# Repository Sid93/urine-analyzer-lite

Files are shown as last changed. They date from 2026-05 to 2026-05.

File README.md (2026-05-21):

# Urine Analyzer Lite

> Compact, automated urine dipstick reader by **Levram Lifesciences**.  
> Single-strip, N20-motor-driven, ESP32-S3 based with thermal print output.

---

## Overview

The Urine Analyzer Lite reads standard 10-pad reagent dipsticks using dual TCS34725 RGB color sensors and classifies results for 10 analytes. A compact N20 gear motor steps the strip under the optical head at controlled speed. Results print via an integrated CSN-A2 thermal printer.

**Key specs:**

| Parameter | Value |
|---|---|
| MCU | ESP32-S3-DevKitC-1 (Xtensa dual-core 240 MHz, 8 MB flash) |
| Sensors | TCS34725 ×2, SHT31, BH1750, ADS1115, HX711 |
| Display | 3.5" SPI TFT (ILI9488) + XPT2046 touch — see `hardware/ENGINEERING_REVIEW.md` |
| Motor | GA12-N20 6V 200RPM with Hall encoder + MX1508 H-bridge |
| Printer | CSN-A2 58mm thermal (ESC/POS) |
| Power | 3.7V 2000mAh LiPo → TP4056 USB-C charger → S13V25F5 5V regulator |
| Sterilization | 275nm UV-C LED (10s cycle post-scan) |
| Analytes | Leukocytes, Nitrites, Urobilinogen, Protein, pH, Blood, Specific Gravity, Ketones, Bilirubin, Glucose |
| Estimated BOM | ~$387 per unit (prototype); target <$250 at 50-unit volume |

---

## Repository Structure

```
urine-analyzer-lite/
├── hardware/
│   ├── schematic/
│   │   ├── gen_schematic.py          # KiCad schematic generator
│   │   └── urine_analyzer_lite.kicad_sch
│   └── cad/
│       └── main_chassis.scad         # OpenSCAD enclosure (all 3D-printed parts)
├── firmware/
│   └── main/
│       ├── main.ino                  # Arduino sketch (state machine)
│       ├── config.h                  # Pin map and tunable constants
│       ├── sensors.h                 # All sensor drivers
│       ├── motor.h                   # N20 motion control + homing
│       ├── analysis.h                # HSV pad classification (10 analytes)
│       └── printer.h                 # ESC/POS thermal print
├── bom/
│   └── bom.csv                       # Full bill of materials (~40 items)
├── TODO.md                           # Project checklist
└── README.md
```

---

## Hardware

### Schematic
Open in KiCad 7+:
```
File → Open → hardware/schematic/urine_analyzer_lite.kicad_sch
```
To regenerate after edits:
```bash
cd hardware/schematic && python3 gen_schematic.py
```

### CAD
Open in OpenSCAD ≥ 2021.01:
```
hardware/cad/main_chassis.scad
```
All 3D-printable parts are exported from one file. Render individual modules:
```
openscad -o chassis_base.stl main_chassis.scad
```

**Print settings:**

| Part | Material | Infill | Layer |
|---|---|---|---|
| Chassis base, MCU tray, dipstick tray | PLA | 20% | 0.2 mm |
| Optical chamber, UV-C shield | Black PLA | 100% | 0.1 mm |
| Sensor mounts, printer bracket, belt parts | PETG | 30% | 0.2 mm |

---

## Firmware

### Requirements
- Arduino IDE ≥ 2.3 with ESP32 board package ≥ 2.0.14
- Board: **ESP32S3 Dev Module** — Flash: 8MB, PSRAM: OPI, USB: Hardware CDC

### Libraries (Arduino Library Manager)
```
Adafruit TCS34725      >= 1.4.2
Adafruit ADS1X15       >= 2.5.0
Adafruit SHT31         >= 2.2.2
BH1750 by Christopher Laws >= 1.3.0
HX711 by bogde         >= 0.7.5
```

### Flash
1. Open `firmware/main/main.ino` in Arduino IDE  
2. Select board and port  
3. Upload

### Calibration (required before first use)
1. **White standard** — place Spectralon pad under optical head; record R/G/B values in `config.h` (`CAL_R/G/B_WHITE`)
2. **Scale** — place known weight on scale platform; adjust `scale.set_scale()` factor in `sensors.h`
3. **Motor steps** — measure real pad pitch with calipers; adjust `TICKS_PER_PAD` in `config.h`
4. **Hue ranges** — run known positive/negative strips; refine `PAD_TABLE[]` in `analysis.h`

---

## Operation

1. Insert dipstick tray with strip face-up
2. Place sample cup on weight sensor (minimum 1 g detected)
3. Press scan button
4. Device homes, steps across all 10 pads, classifies, prints report
5. UV-C sterilization cycle runs automatically (10 s)
6. Remove strip; device returns to IDLE

---

## Bill of Materials

See [`bom/bom.csv`](bom/bom.csv) — estimated prototype total: **$387 USD**.

---

## License

Hardware and firmware © Levram Lifesciences. All rights reserved.  
*For clinical use by qualified personnel only.*

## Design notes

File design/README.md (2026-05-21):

# Design (Stage 3) — Blueprint export

Device design iteration exported from **Blueprint** (lite / single-strip variant).
This is the design-intent source that the hardware (`../hardware/`) and BOM (`../bom/`)
are derived from.

## Contents (`blueprint/`)
- `CONFIG.json` — full device configuration (components, parameters)
- `ELECTRICAL_CONNECTIONS.json` — wiring / net definitions
- `MECHANICAL_CONNECTIONS.json` — mechanical assembly relationships
- `PARTS.csv` — parts list with categories, quantities, costs, source URLs
- `GUIDE.md` — fabrication / wiring / bring-up / assembly checklist
- `VISUAL.png` — rendered layout

> A second, fuller Blueprint export (10P / larger variant) exists outside the repo at
> `~/Desktop/Sids Gdrive/urine_dipstick_analyzer_files (1)/`. Not imported here — this repo
> tracks the **lite** design. Import it if the project consolidates on that variant.

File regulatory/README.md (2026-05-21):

# Regulatory & Quality — Stage 0 Foundation

> Backfilled 2026-05-21. These documents establish the foundation that should have preceded
> the hardware/firmware work. Per the project's hard-gate rule, **Stage 0 gates everything**
> and **design freeze (Stage 5) gates all validation**.

| # | Document | Purpose | Status |
|---|---|---|---|
| 00 | [Target Product Profile](00_target_product_profile.md) | Intended use, analytes, claims, performance targets | DRAFT — open issues |
| 01 | [CDSCO Classification & Pathway](01_cdsco_classification.md) | IVD class (best-guess B), licensing route | DRAFT — needs consultant confirmation |
| 02 | [Standards Matrix](02_standards_matrix.md) | Applicable / excluded standards, tailored | DRAFT |
| 03 | [Risk Management File (ISO 14971)](03_risk_management_iso14971.md) | Hazard analysis / FMEA seed | DRAFT skeleton |
| 04 | [Freedom-to-Operate](04_freedom_to_operate.md) | Preliminary optics patent search | PRELIMINARY |

## The three decisions that gate everything else
1. **Strips: proprietary vs commercial?** (TPP §4) — changes scope, dossier, and timeline most.
2. **Confirm CDSCO class via pre-submission** before generating validation data.
3. **Keep or drop UV-C sterilization?** (Risk H1 / Standards §UV-C) — highest novelty-vs-burden tradeoff.

## Disclaimers
- Best-guess classifications and the FTO read are **not** legal/regulatory opinions.
- Engage a CDSCO regulatory consultant and (before launch/export) a patent attorney.

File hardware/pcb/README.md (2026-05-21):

# PCB — Urine Analyzer Lite (Design A)

A **starting board** generated from the netlist model via KiCad's `pcbnew` Python API.
All 31 footprints are placed and net-assigned; the board is **not yet routed**.

## Files
- `build_pcb.py` — generator (run with KiCad's bundled Python; needs `pcbnew`).
- `urine_analyzer_lite.kicad_pcb` — the board (31 footprints, real footprints, nets assigned).
- `urine_analyzer_lite.kicad_pro` — project file (open this in KiCad).
- `urine_analyzer_lite_render_top.png` — 3D render (top).
- `DRC_report.txt` / `drc.json` — DRC output.

## Validation (KiCad 10.0.3)
- **Schematic parity: 0 mismatches** — the board's connectivity matches the schematic exactly.
- **104 unconnected items** — this is the **unrouted ratsnest** (expected; the engineer routes it).
- **214 DRC violations** — all are **placement-density cosmetics** from the auto-grid layout:
  `silk_over_copper`/`silk_overlap` (ref-text overlap), `courtyards_overlap`,
  `pth_inside_courtyard`, a few `clearance`/`solder_mask_bridge`. They disappear once parts are
  spread out and routed. **None are structural / netlist errors.**

## What the engineer does
1. Open the project in KiCad 10. **Confirm footprints** — modules are generic 2.54mm pin
   headers; verify each header's **pin ORDER against the module datasheet/silkscreen**
   (the auto-assignment uses the netlist order, see `footprints.py` + `../netlist/NETLIST.md`).
2. Re-place parts sensibly (optical chamber sensors together, printer/motor power near the
   regulator, keep UV-C/printer high-current away from sensor analog lines).
3. Add **power planes** (GND / +5V / +3V3), route — wide traces for motor/printer/UV-C per
   `../POWER_BUDGET.md`. Add mounting holes to the chassis stand-offs.
4. **DRC → 0**, then export Gerbers + drill + position:
   ```
   kicad-cli pcb export gerbers -o gerbers/ urine_analyzer_lite.kicad_pcb
   kicad-cli pcb export drill   -o gerbers/ urine_analyzer_lite.kicad_pcb
   ```

## Regenerate
```bash
/Applications/KiCad.app/Contents/Frameworks/Python.framework/Versions/3.9/bin/python3 build_pcb.py
```

> Starting board for engineer verification, not a finished layout. Placement, routing, footprint
> confirmation (esp. module pin order), stackup, and DRC sign-off are the engineer's.

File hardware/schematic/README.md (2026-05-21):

# Schematic — Urine Analyzer Lite (Design A)

`urine_analyzer_lite.kicad_sch` is a **machine-generated, ERC-validated** schematic produced
from the same netlist model as `../netlist/` (single source of truth = `config.h` master pin map).

## Files
- `gen_schematic.py` — generator. Imports `../netlist/gen_netlist.py` (the component/pin/net model).
- `urine_analyzer_lite.kicad_sch` — the schematic (KiCad 9/10, format 20250114).
- `urine_analyzer_lite_schematic.pdf` — rendered view (open without KiCad).
- `ERC_report.txt` — KiCad ERC output.

## Validation (done with KiCad 10.0.3 `kicad-cli`)
- **Netlist cross-check:** KiCad's exported netlist matches the model **39/39 nets** by ref **and pad**.
- **ERC:** **0 errors**, ~18 warnings — all benign: `lib_symbol_issues (ual)` for the custom
  module symbols (embedded, render fine) and `isolated_pin_label: VBUS` (expected single-node
  USB input). Jellybean symbols + all footprints now resolve cleanly.

## Symbols & footprints
- **14 jellybean discretes** (R×5, C, C_Polarized×2, LED, Battery_Cell, Thermistor, SW_Push×3)
  use **real KiCad library symbols** (`Device:*`, `Switch:*`), embedded from KiCad's shared libs.
- **Modules + the MOSFET** use generic rectangular symbols (no stock symbol exists for dev-boards/
  breakouts). Their pins are numbered by **PCB pad** so schematic↔board align.
- **Every symbol has a real footprint** assigned (see `../footprints.py`), so "Update PCB from
  Schematic" carries footprints. Module footprints are 2.54mm pin headers — verify pin ORDER
  against each module's datasheet.

## How connectivity is represented
Every pin carries a **global label = its net name**, placed exactly on the pin's connection point.
KiCad joins global labels by name across the sheet, so the netlist is exact. There are
intentionally **no drawn wires** — a connection-by-label schematic, valid and ERC-clean, but
visually a net-label list rather than a hand-drawn ratsnest (the engineer can redraw with wires;
connectivity won't change).

## What the engineer does next
1. Open in KiCad 9/10. Review nets against `../ENGINEERING_REVIEW.md` and `config.h`.
2. **Swap generic symbols for proper library symbols** where preferred, and **assign real
   footprints** (placeholders listed in `../netlist/NETLIST.md`).
3. Optionally redraw with wires for readability (connectivity won't change — it's label-driven).
4. Re-run ERC, then proceed to PCB layout → DRC → Gerbers (see `../netlist/README.md`).

> This is an AI-generated first draft for verification, not a released design. It is electrically
> correct per the model, but symbol/footprint choices and the physical design need engineer sign-off.

## Regenerate
```bash
python3 gen_schematic.py            # rewrites urine_analyzer_lite.kicad_sch
# then, with KiCad installed:
kicad-cli sch erc urine_analyzer_lite.kicad_sch
kicad-cli sch export pdf -o urine_analyzer_lite_schematic.pdf urine_analyzer_lite.kicad_sch
```

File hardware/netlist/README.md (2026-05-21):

# Netlist — Urine Analyzer Lite (Design A)

Generated from the `config.h` master pin map (see `../ENGINEERING_REVIEW.md §3`).

## Files
- `gen_netlist.py` — generator (single source of truth: the `COMPONENTS` model).
- `urine_analyzer_lite.net` — KiCad legacy netlist. **Import path to PCB layout.**
- `NETLIST.md` — human-readable component + net table for review.

## Regenerate
```bash
python3 gen_netlist.py
```

## How the engineer uses this (Stage 4 verification → layout)
1. **Review** `NETLIST.md` against `ENGINEERING_REVIEW.md` and the firmware `config.h`.
2. In KiCad, create a project; **Pcbnew → File → Import Netlist → `urine_analyzer_lite.net`**.
   This brings in all components + the ratsnest (connectivity) for layout.
3. **Assign real footprints** — the footprints in the netlist are descriptive placeholders.
   Map each to a verified KiCad footprint (or a custom one for the dev-board/module headers).
4. Alternatively, draw the schematic in KiCad's Eeschema from `NETLIST.md`, annotate, and run
   **ERC** — this is the formal Stage 4 schematic-verification step.
5. Then PCB: power planes (GND / +5V / +3V3), wide traces for motor/printer/UV-C, mounting
   holes to the chassis stand-offs, **DRC → 0 errors**, export Gerbers + assembly BOM.

## Known notes for the engineer
- **VBUS** is a single-node net by design: 5V USB input lives on the TP4056 module's own
  USB-C connector; not separately modeled.
- **Footprints are placeholders.** Most parts here are breakout boards / dev modules wired via
  pin headers — expect to create header footprints rather than use bare-IC footprints.
- **Decoupling:** bulk caps (C1/C2 at +5V, C3 at +3V3) are included for the printer/motor
  pulse loads; add per-module 100 nF decoupling at layout as standard practice.
- **Power sequencing constraint** (from `POWER_BUDGET.md`): firmware must keep printer / UV-C /
  heavy-motor phases sequential so peak 5V load stays within the regulator rating.
- This netlist is a **first-draft for verification**, not a released design. An electronics
  engineer must confirm pin mappings, footprints, and run ERC/DRC before fabrication.

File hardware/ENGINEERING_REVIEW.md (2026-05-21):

# Stage 4 Engineering Review — Master Pin Map & Netlist Reconciliation

> Status: DRAFT for engineer verification (2026-05-21).
> **This document is the Stage 4 gate.** Before any PCB layout, an electronics engineer must
> resolve the items marked 🔴 and sign off on the master pin map below. AI-generated; treat as
> a high-quality first draft, NOT release-ready (see project key cautions).

## 0. Why this exists
The electrical design currently lives in three places that **disagree with each other**:
- `firmware/main/config.h` — the firmware pin map (internally consistent, testable)
- `design/blueprint/ELECTRICAL_CONNECTIONS.json` — Blueprint netlist
- `bom/bom.csv` + `README.md` — the parts list

There is also a non-matching legacy schematic (`hardware/schematic/...kicad_sch`, a graphical
mock-up with no netlist) and a separate, divergent camera-based KiCad project
(`~/Desktop/urine_dipstick_analyzer_pcb/`, ESP32-WROOM + OV2640). None can go to PCB as-is.

**Decision: `config.h` is adopted as the source of truth** (it is concrete, internally
consistent, and what the firmware actually drives), corrected for the hardware-validity issues
in §2. All other sources are reconciled to it.

## 1. Source conflicts (resolved → see §3)

| Item | config.h | Blueprint | BOM/README | Resolution |
|---|---|---|---|---|
| Motor driver | MX1508 | L298N mini | MX1508 | **MX1508** (cheaper, adequate for N20; matches firmware/BOM) |
| I2C SDA/SCL | 21 / **22** | 1 / 2 | — | Move to valid pins — see §2.1 |
| Motor IN1/IN2 | 18 / 8 | 4 / 5 | — | Use config.h, remapped in §3 |
| Encoder A/B | 15 / 7 | 6 / 7 | — | Use §3 map |
| HX711 DT/SCK | 4 / 5 | 19 / 20 | — | config.h (Blueprint uses USB pins) |
| Printer TX/RX | 6 / **19** | RX←17 | — | Move RX off USB pin — §2.2 |
| UV-C enable | **3** | (3=button) | — | Move off strapping pin — §2.3 |
| Scan button | 9 | 3 | — | GPIO 16 in §3 |
| Display | 4.3" DSI | 4.3" on I2C | DSI | ✅ RESOLVED: 3.5" SPI TFT (ILI9488) — §2.4 |
| TCS34725 ×2 | both 0x29 | both 0x29 | 2× same | 🔴 I2C address clash — needs mux — §2.5 |
| Printer rail | — | 9V | reg=5V only | 🔴 No 9V rail — §2.6 / power budget |

## 2. Hardware-validity issues (🔴 = engineer decision required)

### 2.1 🔴 Invalid I2C pin — GPIO22 does not exist on ESP32-S3
`config.h` sets `PIN_SCL 22`. The ESP32-S3 has **no GPIO22** (its GPIOs are 0–21 and 26–48).
This pin is invalid and would not compile/route correctly. → Reassign (see §3: SDA=1, SCL=2).

### 2.2 🔴 Printer RX on USB pin — GPIO19
`config.h` `PIN_PRINTER_RX 19`. GPIO19 = USB **D+** on ESP32-S3. The README specifies
"USB: Hardware CDC", so GPIO19/20 are consumed by native USB and cannot also be UART.
→ Move printer UART to a free pair (§3: TX=17, RX=18).

### 2.3 🔴 UV-C enable on strapping pin — GPIO3
GPIO3 is a boot strapping pin (JTAG source select). Driving it at boot can affect startup.
UV-C is a *safety-critical* output and must not glitch on. → Move to GPIO13 with a hardware
pull-down so UV-C is guaranteed OFF at boot (also a risk control — see risk file H1).

### 2.4 ✅ RESOLVED — Display = 3.5" SPI TFT (ILI9488)
Original spec (Waveshare 4.3" MIPI-DSI) was unbuildable: the ESP32-S3 has no MIPI-DSI
peripheral, and the Blueprint's "4.3" on I2C" is also invalid (a graphical panel can't run on I2C).
**Decision (2026-05-21): switch to a 3.5" SPI TFT, ILI9488 (or ST7796 4.0") with XPT2046 touch.**
- Native to ESP32-S3 over SPI; touch shares the SPI bus, IRQ polled (saves a pin).
- BOM updated (LCD1 → SPI TFT); pins assigned in §3.
- Firmware display UI (TODO "Implement display UI") should target LVGL/LovyanGFX on SPI.

### 2.5 🔴 Two TCS34725 share I2C address 0x29
Both color sensors default to 0x29 and the part has no address-select pin. The firmware comment
("multiplex by enabling the LED on one at a time") does **not** change the I2C address — two
devices at 0x29 on one bus is an unresolvable bus clash. → Add a **TCA9548A I2C mux** (addr 0x70)
and put each TCS34725 on its own channel. **This part is missing from the BOM — add it.**
(Alternative: a single sensor on a moving optical head; but dual-sensor differential is a stated design intent.)

### 2.6 🔴 Missing 9V printer rail
Blueprint shows the CSN-A2 printer on 9V, but the only regulator (S13V25F5) outputs 5V.
The CSN-A2 runs 5–9V; at 5V it prints (slightly slower/lighter). → Recommend **running the
printer at 5V** and deleting the 9V requirement, OR add a dedicated boost converter. See power budget.

## 3. Proposed master pin map (ESP32-S3, USB-CDC enabled) — VERIFY BEFORE LAYOUT

Avoids: GPIO 0/45/46 (strapping), 3 (strapping), 19/20 (USB), 22–25 (don't exist),
26–37 (SPI flash + octal PSRAM on N8R8). All assignments below are valid, free S3 GPIOs.

| Function | Net | GPIO | Notes |
|---|---|---|---|
| I2C SDA | `I2C_SDA` | 1 | shared bus: mux, SHT31, BH1750, ADS1115 |
| I2C SCL | `I2C_SCL` | 2 | |
| Motor IN1 (PWM) | `MOT_IN1` | 4 | MX1508 |
| Motor IN2 (PWM) | `MOT_IN2` | 5 | MX1508 |
| Encoder A | `ENC_A` | 6 | |
| Encoder B | `ENC_B` | 7 | |
| Limit home | `LIM_HOME` | 10 | INPUT_PULLUP, active-LOW |
| Limit end | `LIM_END` | 11 | INPUT_PULLUP, active-LOW |
| Illum LED PWM | `LED_PWM` | 12 | gate of 2N7000 |
| UV-C enable | `UVC_EN` | 13 | + 10k pull-DOWN; off at boot (safety) |
| HX711 DT | `HX_DT` | 14 | |
| HX711 SCK | `HX_SCK` | 15 | |
| Scan button | `SCAN_BTN` | 16 | INPUT_PULLUP, active-LOW |
| Printer TX (→RXD) | `PRN_TX` | 17 | UART1 |
| Printer RX (←TXD) | `PRN_RX` | 18 | UART1 |
| TFT SCLK | `TFT_SCLK` | 38 | SPI TFT (ILI9488) |
| TFT MOSI | `TFT_MOSI` | 39 | |
| TFT MISO | `TFT_MISO` | 40 | shared with touch read |
| TFT CS | `TFT_CS` | 41 | |
| TFT DC | `TFT_DC` | 42 | |
| TFT backlight | `TFT_BL` | 47 | enable / PWM |
| Touch CS | `TOUCH_CS` | 48 | XPT2046; IRQ polled |
| TFT reset | `TFT_RST` | 21 | |

I2C addresses: TCA9548A 0x70 → ch0/ch1 = TCS34725 (0x29 each); SHT31 0x44; BH1750 0x23; ADS1115 0x48. No clashes.
All display + I/O pins above are valid, free ESP32-S3 GPIOs and match `firmware/main/config.h`.

## 4. What remains for a real Stage 4 (after this is signed off)
1. Engineer resolves all 🔴 items and approves §3 map.
2. ✅ Netlist generated from the master pin map → `hardware/netlist/` (`urine_analyzer_lite.net`
   importable into Pcbnew, plus `NETLIST.md`). Footprints are placeholders to confirm in KiCad.
3. ✅ Schematic generated + **ERC-clean (0 errors)** → `hardware/schematic/` (+ PDF). Jellybean
   discretes use real `Device:`/`Switch:` library symbols; all parts have **real footprints**.
   KiCad netlist matches the model 39/39 by ref+pad.
4. ✅ **Starting PCB generated** → `hardware/pcb/urine_analyzer_lite.kicad_pcb` (+ project, render).
   31 footprints placed + net-assigned; **schematic-parity 0**. Unrouted (104-net ratsnest) and
   auto-grid placement (cosmetic DRC). Engineer: confirm module header pin order, place, route,
   power planes, DRC→0, Gerbers.
4. PCB layout: power planes (GND/3V3/5V), wide traces for motor/printer/UV-C, mounting holes to chassis.
5. Run **DRC** → 0 errors. Export Gerbers + assembly BOM (JLCPCB/PCBWay).
6. Order 5× prototypes.

> Note for this environment: KiCad / `kicad-cli` is not installed here, so ERC/DRC/Gerber export
> and interactive layout must be done on a workstation with KiCad. I can generate a real
> netlisted schematic *file* programmatically if you want to take that path — say the word.

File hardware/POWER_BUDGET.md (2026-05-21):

# Stage 4 Power Budget & Rail Analysis — Urine Analyzer Lite

> Status: DRAFT for engineer verification (2026-05-21). Numbers are estimates from datasheets/
> typical modules; confirm against actual parts before regulator/battery sizing is frozen.

## 1. Power tree (as designed)

```
LiPo 3.7V 2000mAh ──► TP4056 (USB-C charge only) ──► (LiPo discharges directly)
                                                  │
                              ┌───────────────────┴───────────────────┐
                              ▼                                        
                    S13V25F5 buck-boost  ──►  5V rail (rated 2.5 A max)
                              │
                              ├─► 5V: MCU (5V pin), illum LED, UV-C LED, printer*, motor driver, display
                              └─► 3.3V: ??? (see §3 — no dedicated 3.3V regulator in BOM)
```
\* Blueprint claimed printer on 9V — no 9V rail exists (see Engineering Review §2.6).

## 2. Load estimate (peak)

| Load | Rail | Typical | Peak | Notes |
|---|---|---|---|---|
| ESP32-S3 DevKit | 5V→3V3 | 0.15 A | ~0.5 A | WiFi/BT bursts if enabled |
| High-CRI illum LED | 5V | 0.1 A | 0.1 A | PWM |
| **UV-C 275 nm LED** | 5V | — | ~0.5 A | only during 10 s sterilize |
| **N20 motor (GA12-N20)** | 5V | 0.15 A | ~0.8–1.5 A | stall current; running ~150 mA |
| **CSN-A2 thermal printer** | 5V | 0.5 A | **~1.5–2.0 A** | dominant load; heavy during black print |
| 4.3" display (if kept) | 5V | 0.2 A | ~0.5 A | backlight dominated |
| Sensors (TCS×2, SHT31, BH1750, ADS1115, mux) | 3.3V | <0.05 A | <0.05 A | negligible |
| HX711 + load cell | 3.3V | <0.01 A | <0.01 A | |

## 3. 🔴 Findings (engineer decisions)

1. **No dedicated 3.3V rail.** Sensors are 3.3V but the only regulator outputs 5V. Currently
   they'd draw from the DevKit's onboard 3V3 pin (LDO from 5V/USB), which is limited (~few
   hundred mA) and not meant to power an external sensor bus reliably. → Add a small **3.3V
   regulator** (e.g. AMS1117-3.3 or a buck) fed from 5V, sized for the sensor bus. The legacy
   PCB already used an AMS1117-3.3 — reuse that choice.

2. **Regulator headroom is marginal.** Worst-case *coincident* 5V load:
   printer 2.0 A + motor 0.8 A + MCU 0.5 A + display 0.5 A + LED 0.1 A ≈ **3.9 A**, which
   **exceeds the S13V25F5's 2.5 A rating.** Mitigations:
   - **Sequence high loads** (the state machine already does: SCAN → PRINT → STERILIZE are
     sequential, so printer/UV-C/heavy-motor rarely coincide). Document this as a hard firmware
     constraint, not just current behavior.
   - If coincidence is possible, **up-rate the regulator** (≥4 A) or split rails.

3. **Battery discharge rate.** ~3.9 A peak from a 3.7 V cell ≈ a 2000 mAh pouch at ~**2C**.
   Confirm the cell's continuous + pulse C-rating; add bulk capacitance (e.g. 1000 µF) near the
   printer to absorb print pulses. Under-rated cells will sag and brown-out the MCU.

4. **TP4056 is a charger, not a system-power-path IC.** It does not provide load-sharing /
   power-path management. While charging, simultaneous heavy load can confuse charge
   termination. → Consider a power-path charger (e.g. a TP4056-with-protection + ideal-diode,
   or an IP5306/BQ24074-class IC) if the device must operate while charging.

5. **Brown-out protection.** Enable ESP32-S3 brown-out detector and gate the printer/UV-C so a
   sagging rail can't trigger a mid-cycle reset that leaves UV-C on (safety, risk file H1/H7).

## 4. Recommended actions before layout
- [ ] Add 3.3V regulator (AMS1117-3.3 or buck) to BOM + schematic.
- [ ] Add TCA9548A I2C mux to BOM (from Engineering Review §2.5).
- [ ] Decide printer rail: run at 5V (preferred) or add 9V boost.
- [ ] Confirm LiPo C-rating ≥ peak draw; add bulk caps at printer + motor.
- [ ] Decide regulator sizing vs. enforced load-sequencing; document the sequencing constraint.
- [ ] Resolve display (Engineering Review §2.4) — affects pin count and 5V budget.

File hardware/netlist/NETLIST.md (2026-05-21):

# Netlist — Urine Analyzer Lite (Design A)

> Auto-generated by `gen_netlist.py` from the `config.h` master pin map.
> For engineer verification. Footprints are placeholders — confirm in KiCad.

## Components

| Ref | Value | Footprint | Description |
|---|---|---|---|
| U1 | ESP32-S3-DevKitC-1 | `Connector_PinHeader_2.54mm:PinHeader_2x22_P2.54mm_Vertical` | Main MCU (USB-CDC enabled) |
| BT1 | LiPo 3.7V 2000mAh | `Connector_JST:JST_PH_S2B-PH-K_1x02_P2.00mm_Horizontal` | Main battery |
| U2 | TP4056 USB-C | `Connector_PinHeader_2.54mm:PinHeader_1x06_P2.54mm_Vertical` | LiPo charger (charge path only) |
| U3 | S13V25F5 buck-boost | `Connector_PinHeader_2.54mm:PinHeader_1x04_P2.54mm_Vertical` | 5V 2.5A regulator |
| U12 | AMS1117-3.3 | `Package_TO_SOT_SMD:SOT-223-3_TabPin2` | 3.3V LDO for sensor bus |
| C1 | 1000uF/10V | `Capacitor_THT:CP_Radial_D10.0mm_P5.00mm` | Bulk cap at 5V (printer pulse) |
| C2 | 470uF/10V | `Capacitor_THT:CP_Radial_D8.0mm_P3.50mm` | Bulk cap at motor driver |
| C3 | 10uF/10V | `Capacitor_SMD:C_0805_2012Metric` | AMS1117 output cap |
| U11 | TCA9548A | `Connector_PinHeader_2.54mm:PinHeader_1x12_P2.54mm_Vertical` | I2C mux (addr 0x70) |
| U4 | TCS34725 | `Connector_PinHeader_2.54mm:PinHeader_1x04_P2.54mm_Vertical` | RGB sensor #1 (mux ch0) |
| U5 | TCS34725 | `Connector_PinHeader_2.54mm:PinHeader_1x04_P2.54mm_Vertical` | RGB sensor #2 (mux ch1) |
| U6 | SHT31-D | `Connector_PinHeader_2.54mm:PinHeader_1x05_P2.54mm_Vertical` | Temp/humidity (0x44) |
| U7 | BH1750 | `Connector_PinHeader_2.54mm:PinHeader_1x05_P2.54mm_Vertical` | Ambient light (0x23) |
| U8 | ADS1115 | `Connector_PinHeader_2.54mm:PinHeader_1x06_P2.54mm_Vertical` | 16-bit ADC (0x48) |
| RT1 | NTC 10k B3950 | `Resistor_THT:R_Axial_DIN0207_L6.3mm_D2.5mm_P7.62mm_Horizontal` | Optical chamber temp |
| R1 | 10k | `Resistor_SMD:R_0805_2012Metric` | NTC divider lower leg |
| U9 | MX1508 | `Connector_PinHeader_2.54mm:PinHeader_1x06_P2.54mm_Vertical` | Dual H-bridge (one channel used) |
| M1 | GA12-N20 6V 200RPM +enc | `Connector_PinHeader_2.54mm:PinHeader_1x06_P2.54mm_Vertical` | Strip transport motor |
| SW1 | KW12-3 | `Connector_PinHeader_2.54mm:PinHeader_1x02_P2.54mm_Vertical` | Home limit (active-LOW) |
| SW2 | KW12-3 | `Connector_PinHeader_2.54mm:PinHeader_1x02_P2.54mm_Vertical` | End limit (active-LOW) |
| D1 | High-CRI 95+ LED | `LED_THT:LED_D5.0mm_Clear` | Pad illumination |
| R2 | 100R | `Resistor_SMD:R_0805_2012Metric` | LED current limit |
| Q1 | 2N7000 | `Package_TO_SOT_THT:TO-92_Inline` | LED PWM low-side switch |
| R3 | 220R | `Resistor_SMD:R_0805_2012Metric` | MOSFET gate series |
| R4 | 100k | `Resistor_SMD:R_0805_2012Metric` | MOSFET gate pulldown |
| D2 | 275nm UVC module | `Connector_PinHeader_2.54mm:PinHeader_1x03_P2.54mm_Vertical` | Tray sterilization |
| R5 | 100k | `Resistor_SMD:R_0805_2012Metric` | UV-C EN pulldown (OFF at boot) |
| U10 | HX711 1kg kit | `Connector_PinHeader_2.54mm:PinHeader_1x04_P2.54mm_Vertical` | Sample weight |
| PR1 | CSN-A2 thermal | `Connector_PinHeader_2.54mm:PinHeader_1x04_P2.54mm_Vertical` | Report printout |
| LCD1 | 3.5in SPI TFT ILI9488 +touch | `Connector_PinHeader_2.54mm:PinHeader_1x13_P2.54mm_Vertical` | UI display |
| SW3 | Tactile 6x6 | `Connector_PinHeader_2.54mm:PinHeader_1x02_P2.54mm_Vertical` | Scan trigger (active-LOW) |

## Nets

| Net | Connections (ref.pin = name) |
|---|---|
| **+3V3** | U12.2 (VOUT), C3.1 (1), U11.1 (VCC), U11.5 (RESET), U4.1 (VIN), U5.1 (VIN), U6.1 (VIN), U7.1 (VCC), U8.1 (VDD), RT1.1 (1), M1.3 (VCC), U10.1 (VCC) |
| **+5V** | U1.1 (5V), U3.3 (VOUT), U3.4 (EN), U12.3 (VIN), C1.1 (+), C2.1 (+), U9.1 (VCC), D1.2 (A), D2.1 (VIN), PR1.1 (VH), LCD1.1 (VCC) |
| **ENC_A** | U1.8 (GPIO6), M1.5 (C1) |
| **ENC_B** | U1.9 (GPIO7), M1.6 (C2) |
| **GND** | U1.2 (GND), U1.3 (GND), BT1.2 (-), U2.2 (GND), U2.4 (BAT-), U2.6 (OUT-), U3.2 (GND), U12.1 (GND), C1.2 (-), C2.2 (-), C3.2 (2), U11.2 (GND), U11.6 (A0), U11.7 (A1), U11.8 (A2), U4.2 (GND), U5.2 (GND), U6.2 (GND), U6.5 (ADR), U7.2 (GND), U7.5 (ADDR), U8.2 (GND), U8.5 (ADDR), R1.2 (2), U9.2 (GND), M1.4 (GND), SW1.1 (COM), SW2.1 (COM), Q1.1 (S), R4.2 (2), D2.2 (GND), R5.2 (2), U10.2 (GND), PR1.2 (GND), LCD1.2 (GND), SW3.2 (2) |
| **HX_DT** | U1.14 (GPIO14), U10.3 (DT) |
| **HX_SCK** | U1.15 (GPIO15), U10.4 (SCK) |
| **I2C_SCL** | U1.5 (GPIO2), U11.4 (SCL), U6.4 (SCL), U7.4 (SCL), U8.4 (SCL) |
| **I2C_SDA** | U1.4 (GPIO1), U11.3 (SDA), U6.3 (SDA), U7.3 (SDA), U8.3 (SDA) |
| **LED_DRAIN** | R2.2 (2), Q1.3 (D) |
| **LED_GATE** | Q1.2 (G), R3.2 (2), R4.1 (1) |
| **LED_NODE** | D1.1 (K), R2.1 (1) |
| **LED_PWM** | U1.12 (GPIO12), R3.1 (1) |
| **LIM_END** | U1.11 (GPIO11), SW2.2 (NO) |
| **LIM_HOME** | U1.10 (GPIO10), SW1.2 (NO) |
| **MOTOR_A** | U9.5 (OUT1), M1.1 (M1) |
| **MOTOR_B** | U9.6 (OUT2), M1.2 (M2) |
| **MOT_IN1** | U1.6 (GPIO4), U9.3 (IN1) |
| **MOT_IN2** | U1.7 (GPIO5), U9.4 (IN2) |
| **NTC_SENSE** | U8.6 (A0), RT1.2 (2), R1.1 (1) |
| **PRN_RX** | U1.18 (GPIO18), PR1.4 (TX) |
| **PRN_TX** | U1.17 (GPIO17), PR1.3 (RX) |
| **SCAN_BTN** | U1.16 (GPIO16), SW3.1 (1) |
| **TCS1_SCL** | U11.10 (SC0), U4.4 (SCL) |
| **TCS1_SDA** | U11.9 (SD0), U4.3 (SDA) |
| **TCS2_SCL** | U11.12 (SC1), U5.4 (SCL) |
| **TCS2_SDA** | U11.11 (SD1), U5.3 (SDA) |
| **TFT_BL** | U1.25 (GPIO47), LCD1.8 (LED) |
| **TFT_CS** | U1.23 (GPIO41), LCD1.3 (CS) |
| **TFT_DC** | U1.24 (GPIO42), LCD1.5 (DC) |
| **TFT_MISO** | U1.22 (GPIO40), LCD1.9 (SDO), LCD1.13 (T_DO) |
| **TFT_MOSI** | U1.21 (GPIO39), LCD1.6 (SDI), LCD1.12 (T_DIN) |
| **TFT_RST** | U1.19 (GPIO21), LCD1.4 (RESET) |
| **TFT_SCLK** | U1.20 (GPIO38), LCD1.7 (SCK), LCD1.10 (T_CLK) |
| **TOUCH_CS** | U1.26 (GPIO48), LCD1.11 (T_CS) |
| **UVC_EN** | U1.13 (GPIO13), D2.3 (EN), R5.1 (1) |
| **VBAT** | BT1.1 (+), U2.3 (BAT+) |
| **VBUS** | U2.1 (VBUS) |
| **VSYS** | U2.5 (OUT+), U3.1 (VIN) |

_Total: 31 components, 39 nets._

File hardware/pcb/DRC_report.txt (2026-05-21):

** Drc report for urine_analyzer_lite.kicad_pcb **
** Created on 2026-05-21T16:20:34 **
** Report includes: Errors, Warnings **

** Found 214 DRC violations **
[clearance]: Clearance violation ( clearance 0.2000 mm; actual 0.0000 mm)
    Local override; error
    @(30.0000 mm, 72.0000 mm): PTH pad 1 [+5V] of C2
    @(30.0000 mm, 70.6400 mm): PTH pad 33 [<no net>] of U1
[clearance]: Clearance violation ( clearance 0.2000 mm; actual 0.0000 mm)
    Local override; error
    @(30.0000 mm, 72.0000 mm): PTH pad 1 [+5V] of C2
    @(30.0000 mm, 73.1800 mm): PTH pad 35 [<no net>] of U1
[clearance]: Clearance violation ( clearance 0.2000 mm; actual 0.0147 mm)
    Local override; error
    @(33.5000 mm, 72.0000 mm): PTH pad 2 [GND] of C2
    @(32.5400 mm, 70.6400 mm): PTH pad 34 [<no net>] of U1
[clearance]: Clearance violation ( clearance 0.2000 mm; actual 0.0000 mm)
    Local override; error
    @(33.5000 mm, 72.0000 mm): PTH pad 2 [GND] of C2
    @(32.5400 mm, 73.1800 mm): PTH pad 36 [<no net>] of U1
[courtyards_overlap]: Courtyards overlap
    Rule: board setup constraints courtyard; error
    @(30.0000 mm, 30.0000 mm): Footprint U1
    @(30.0000 mm, 72.0000 mm): Footprint C2
[pth_inside_courtyard]: PTH inside courtyard
    Local override; error
    @(30.0000 mm, 72.0000 mm): PTH pad 1 [+5V] of C2
    @(30.0000 mm, 30.0000 mm): Footprint U1
[pth_inside_courtyard]: PTH inside courtyard
    Local override; error
    @(33.5000 mm, 72.0000 mm): PTH pad 2 [GND] of C2
    @(30.0000 mm, 30.0000 mm): Footprint U1
[pth_inside_courtyard]: PTH inside courtyard
    Local override; error
    @(30.0000 mm, 68.1000 mm): PTH pad 31 [<no net>] of U1
    @(30.0000 mm, 72.0000 mm): Footprint C2
[pth_inside_courtyard]: PTH inside courtyard
    Local override; error
    @(32.5400 mm, 68.1000 mm): PTH pad 32 [<no net>] of U1
    @(30.0000 mm, 72.0000 mm): Footprint C2
[pth_inside_courtyard]: PTH inside courtyard
    Local override; error
    @(30.0000 mm, 70.6400 mm): PTH pad 33 [<no net>] of U1
    @(30.0000 mm, 72.0000 mm): Footprint C2
[pth_inside_courtyard]: PTH inside courtyard
    Local override; error
    @(32.5400 mm, 70.6400 mm): PTH pad 34 [<no net>] of U1
    @(30.0000 mm, 72.0000 mm): Footprint C2
[pth_inside_courtyard]: PTH inside courtyard
    Local override; error
    @(30.0000 mm, 73.1800 mm): PTH pad 35 [<no net>] of U1
    @(30.0000 mm, 72.0000 mm): Footprint C2
[pth_inside_courtyard]: PTH inside courtyard
    Local override; error
    @(32.5400 mm, 73.1800 mm): PTH pad 36 [<no net>] of U1
    @(30.0000 mm, 72.0000 mm): Footprint C2
[pth_inside_courtyard]: PTH inside courtyard
    Local override; error
    @(30.0000 mm, 75.7200 mm): PTH pad 37 [<no net>] of U1
    @(30.0000 mm, 72.0000 mm): Footprint C2
[pth_inside_courtyard]: PTH inside courtyard
    Local override; error
    @(32.5400 mm, 75.7200 mm): PTH pad 38 [<no net>] of U1
    @(30.0000 mm, 72.0000 mm): Footprint C2
[solder_mask_bridge]: Front solder mask aperture bridges items with different nets
    Rule: board setup solder mask min width; error
    @(30.0000 mm, 72.0000 mm): PTH pad 1 [+5V] of C2
    @(30.0000 mm, 70.6400 mm): PTH pad 33 [<no net>] of U1
[solder_mask_bridge]: Front solder mask aperture bridges items with different nets
    Rule: board setup solder mask min width; error
    @(30.0000 mm, 72.0000 mm): PTH pad 1 [+5V] of C2
    @(30.0000 mm, 73.1800 mm): PTH pad 35 [<no net>] of U1
[solder_mask_bridge]: Rear solder mask aperture bridges items with different nets
    Rule: board setup solder mask min width; error
    @(30.0000 mm, 72.0000 mm): PTH pad 1 [+5V] of C2
    @(30.0000 mm, 70.6400 mm): PTH pad 33 [<no net>] of U1
[solder_mask_bridge]: Rear solder mask aperture bridges items with different nets
    Rule: board setup solder mask min width; error
    @(30.0000 mm, 72.0000 mm): PTH pad 1 [+5V] of C2
    @(30.0000 mm, 73.1800 mm): PTH pad 35 [<no net>] of U1
[solder_mask_bridge]: Front solder mask aperture bridges items with different nets
    Rule: board setup solder mask min width; error
    @(33.5000 mm, 72.0000 mm): PTH pad 2 [GND] of C2
    @(32.5400 mm, 73.1800 mm): PTH pad 36 [<no net>] of U1
[solder_mask_bridge]: Rear solder mask aperture bridges items with different nets
    Rule: board setup solder mask min width; error
    @(33.5000 mm, 72.0000 mm): PTH pad 2 [GND] of C2
    @(32.5400 mm, 73.1800 mm): PTH pad 36 [<no net>] of U1
[silk_overlap]: Silkscreen clearance
    Rule: board setup constraints silk; warning
    @(31.7500 mm, 72.0000 mm): Circle of C2 on F.Silkscreen
    @(28.6200 mm, 31.2700 mm): Segment of U1 on F.Silkscreen
[silk_overlap]: Silkscreen clearance
    Rule: board setup constraints silk; warning
    @(33.9200 mm, 28.6200 mm): Segment of U1 on F.Silkscreen
    @(33.9900 mm, 73.0400 mm): Segment of C2 on F.Silkscreen
[silk_overlap]: Silkscreen clearance
    Rule: board setup constraints silk; warning
    @(31.7500 mm, 72.0000 mm): Circle of C2 on F.Silkscreen
    @(33.9200 mm, 28.6200 mm): Segment of U1 on F.Silkscreen
[silk_overlap]: Silkscreen clearance
    Rule: board setup constraints silk; warning
    @(33.8300 mm, 68.4840 mm): Segment of C2 on F.Silkscreen
    @(33.9200 mm, 28.6200 mm): Segment of U1 on F.Silkscreen
[silk_overlap]: Silkscreen clearance
    Rule: board setup constraints silk; warning
    @(33.8700 mm, 68.5070 mm): Segment of C2 on F.Silkscreen
    @(33.9200 mm, 28.6200 mm): Segment of U1 on F.Silkscreen
[silk_overlap]: Silkscreen clearance
    Rule: board setup constraints silk; warning
    @(33.9200 mm, 28.6200 mm): Segment of U1 on F.Silkscreen
    @(33.9100 mm, 68.5320 mm): Segment of C2 on F.Silkscreen
[silk_overlap]: Silkscreen clearance
    Rule: board setup constraints silk; warning
    @(33.9200 mm, 28.6200 mm): Segment of U1 on F.Silkscreen
    @(33.9500 mm, 68.5570 mm): Segment of C2 on F.Silkscreen
[silk_overlap]: Silkscreen clearance
    Rule: board setup constraints silk; warning
    @(33.9200 mm, 28.6200 mm): Segment of U1 on F.Silkscreen
    @(33.9900 mm, 68.5820 mm): Segment of C2 on F.Silkscreen
[silk_overlap]: Silkscreen clearance
    Rule: board setup constraints silk; warning
    @(33.8300 mm, 73.0400 mm): Segment of C2 on F.Silkscreen
    @(33.9200 mm, 28.6200 mm): Segment of U1 on F.Silkscreen
[silk_overlap]: Silkscreen clearance
    Rule: board setup constraints silk; warning
    @(33.8700 mm, 73.0400 mm): Segment of C2 on F.Silkscreen
    @(33.9200 mm, 28.6200 mm): Segment of U1 on F.Silkscreen
[silk_overlap]: Silkscreen clearance
    Rule: board setup constraints silk; warning
    @(33.9200 mm, 28.6200 mm): Segment of U1 on F.Silkscreen
    @(33.9100 mm, 73.0400 mm): Segment of C2 on F.Silkscreen
[silk_overlap]: Silkscreen clearance
    Rule: board setup constraints silk; warning
    @(33.9200 mm, 28.6200 mm): Segment of U1 on F.Silkscreen
    @(33.9500 mm, 73.0400 mm): Segment of C2 on F.Silkscreen
[silk_overlap]: Silkscreen clearance
    Rule: board setup constraints silk; warning
    @(33.9200 mm, 28.6200 mm): Segment of U1 on F.Silkscreen
    @(34.0300 mm, 68.6080 mm): Segment of C2 on F.Silkscreen
[silk_overlap]: Silkscreen clearance
    Rule: board setup constraints silk; warning
    @(33.9200 mm, 28.6200 mm): Segment of U1 on F.Silkscreen
    @(34.0300 mm, 73.0400 mm): Segment of C2 on F.Silkscreen
[silk_over_copper]: Silkscreen clipped by solder mask
    Local override; warning
    @(31.7500 mm, 66.7500 mm): Reference field of C2
    @(32.5400 mm, 65.5600 mm): PTH pad 30 [<no net>] of U1
[silk_over_copper]: Silkscreen clipped by solder mask
    Local override; warning
    @(31.7500 mm, 66.7500 mm): Reference field of C2
    @(32.5400 mm, 68.1000 mm): PTH pad 32 [<no net>] of U1
[silk_over_copper]: Silkscreen clipped by solder mask
    Local override; warning
    @(33.9200 mm, 28.6200 mm): Segment of U1 on F.Silkscreen
    @(33.5000 mm, 72.0000 mm): PTH pad 2 [GND] of C2
[silk_over_copper]: Silkscreen clipped by solder mask
    Local override; warning
    @(32.5500 mm, 73.0400 mm): Segment of C2 on F.Silkscreen
    @(32.5400 mm, 73.1800 mm): PTH pad 36 [<no net>] of U1
[silk_over_copper]: Silkscreen clipped by solder mask
    Local override; warning
    @(32.5500 mm, 73.0400 mm): Segment of C2 on F.Silkscreen
    @(32.5400 mm, 75.7200 mm): PTH pad 38 [<no net>] of U1
[silk_over_copper]: Silkscreen clipped by solder mask
    Local override; warning
    @(31.7500 mm, 72.0000 mm): Circle of C2 on F.Silkscreen
    @(30.0000 mm, 68.1000 mm): PTH pad 31 [<no net>] of U1
[silk_over_copper]: Silkscreen clipped by solder mask
    Local override; warning
    @(31.7500 mm, 72.0000 mm): Circle of C2 on F.Silkscreen
    @(32.5400 mm, 68.1000 mm): PTH pad 32 [<no net>] of U1
[silk_over_copper]: Silkscreen clipped by solder mask
    Local override; warning
    @(31.7500 mm, 72.0000 mm): Circle of C2 on F.Silkscreen
    @(30.0000 mm, 75.7200 mm): PTH pad 37 [<no net>] of U1
[silk_over_copper]: Silkscreen clipped by solder mask
    Local override; warning
    @(31.7500 mm, 72.0000 mm): Circle of C2 on F.Silkscreen
    @(32.5400 mm, 75.7200 mm): PTH pad 38 [<no net>] of U1
[silk_over_copper]: Silkscreen clipped by solder mask
    Local override; warning
    @(31.7500 mm, 67.9200 mm): Segment of C2 on F.Silkscreen
    @(32.5400 mm, 68.1000 mm): PTH pad 32 [<no net>] of U1
[silk_over_copper]: Silkscreen clipped by solder mask
    Local override; warning
    @(31.7500 mm, 67.9200 mm): Segment of C2 on F.Silkscreen
    @(32.5400 mm, 70.6400 mm): PTH pad 34 [<no net>] of U1
[silk_over_copper]: Silkscreen clipped by solder mask
    Local override; warning
    @(31.7500 mm, 67.9200 mm): Segment of C2 on F.Silkscreen
    @(32.5400 mm, 73.1800 mm): PTH pad 36 [<no net>] of U1
[silk_over_copper]: Silkscreen clipped by solder mask
    Local override; warning
    @(31.7500 mm, 67.9200 mm): Segment of C2 on F.Silkscreen
    @(32.5400 mm, 75.7200 mm): PTH pad 38 [<no net>] of U1
[silk_over_copper]: Silkscreen clipped by solder mask
    Local override; warning
    @(31.7900 mm, 67.9200 mm): Segment of C2 on F.Silkscreen
    @(32.5400 mm, 68.1000 mm): PTH pad 32 [<no net>] of U1
[silk_over_copper]: Silkscreen clipped by solder mask
    Local override; warning
    @(31.7900 mm, 67.9200 mm): Segment of C2 on F.Silkscreen
    @(32.5400 mm, 70.6400 mm): PTH pad 34 [<no net>] of U1
[silk_over_copper]: Silkscreen clipped by solder mask
    Local override; warning
    @(31.7900 mm, 67.9200 mm): Segment of C2 on F.Silkscreen
    @(32.5400 mm, 73.1800 mm): PTH pad 36 [<no net>] of U1
[silk_over_copper]: Silkscreen clipped by solder mask
    Local override; warning
    @(31.7900 mm, 67.9200 mm): Segment of C2 on F.Silkscreen
    @(32.5400 mm, 75.7200 mm): PTH pad 38 [<no net>] of U1
[silk_over_copper]: Silkscreen clipped by solder mask
    Local override; warning
    @(31.8300 mm, 67.9210 mm): Segment of C2 on F.Silkscreen
    @(32.5400 mm, 68.1000 mm): PTH pad 32 [<no net>] of U1
[silk_over_copper]: Silkscreen clipped by solder mask
    Local override; warning
    @(31.8300 mm, 67.9210 mm): Segment of C2 on F.Silkscreen
    @(32.5400 mm, 70.6400 mm): PTH pad 34 [<no net>] of U1
[silk_over_copper]: Silkscreen clipped by solder mask
    Local override; warning
    @(31.8300 mm, 67.9210 mm): Segment of C2 on F.Silkscreen
    @(32.5400 mm, 73.1800 mm): PTH pad 36 [<no net>] of U1
[silk_over_copper]: Silkscreen clipped by solder mask
    Local override; warning
    @(31.8300 mm, 67.9210 mm): Segment of C2 on F.Silkscreen
    @(32.5400 mm, 75.7200 mm): PTH pad 38 [<no net>] of U1
[silk_over_copper]: Silkscreen clipped by solder mask
    Local override; warning
    @(32.0700 mm, 67.9320 mm): Segment of C2 on F.Silkscreen
    @(32.5400 mm, 68.1000 mm): PTH pad 32 [<no net>] of U1
[silk_over_copper]: Silkscreen clipped by solder mask
    Local override; warning
    @(32.0700 mm, 67.9320 mm): Segment of C2 on F.Silkscreen
    @(32.5400 mm, 70.6400 mm): PTH pad 34 [<no net>] of U1
[silk_over_copper]: Silkscreen clipped by solder mask
    Local override; warning
    @(32.0700 mm, 67.9320 mm): Segment of C2 on F.Silkscreen
    @(32.5400 mm, 73.1800 mm): PTH pad 36 [<no net>] of U1
[silk_over_copper]: Silkscreen clipped by solder mask
    Local override; warning
    @(32.0700 mm, 67.9320 mm): Segment of C2 on F.Silkscreen
    @(32.5400 mm, 75.7200 mm): PTH pad 38 [<no net>] of U1
[silk_over_copper]: Silkscreen clipped by solder mask
    Local override; warning
    @(32.1100 mm, 67.9360 mm): Segment of C2 on F.Silkscreen
    @(32.5400 mm, 68.1000 mm): PTH pad 32 [<no net>] of U1
[silk_over_copper]: Silkscreen clipped by solder mask
    Local override; warning
    @(32.1100 mm, 67.9360 mm): Segment of C2 on F.Silkscreen
    @(32.5400 mm, 70.6400 mm): PTH pad 34 [<no net>] of U1
[silk_over_copper]: Silkscreen clipped by solder mask
    Local override; warning
    @(32.1100 mm, 67.9360 mm): Segment of C2 on F.Silkscreen
    @(32.5400 mm, 73.1800 mm): PTH pad 36 [<no net>] of U1
[silk_over_copper]: Silkscreen clipped by solder mask
    Local override; warning
    @(32.1100 mm, 67.9360 mm): Segment of C2 on F.Silkscreen
    @(32.5400 mm, 75.7200 mm): PTH pad 38 [<no net>] of U1
[silk_over_copper]: Silkscreen clipped by solder mask
    Local override; warning
    @(32.1500 mm, 67.9390 mm): Segment of C2 on F.Silkscreen
    @(32.5400 mm, 68.1000 mm): PTH pad 32 [<no net>] of U1
[silk_over_copper]: Silkscreen clipped by solder mask
    Local override; warning
    @(32.1500 mm, 67.9390 mm): Segment of C2 on F.Silkscreen
    @(32.5400 mm, 70.6400 mm): PTH pad 34 [<no net>] of U1
[silk_over_copper]: Silkscreen clipped by solder mask
    Local override; warning
    @(32.1500 mm, 67.9390 mm): Segment of C2 on F.Silkscreen
    @(32.5400 mm, 73.1800 mm): PTH pad 36 [<no net>] of U1
[silk_over_copper]: Silkscreen clipped by solder mask
    Local override; warning
    @(32.1500 mm, 67.9390 mm): Segment of C2 on F.Silkscreen
    @(32.5400 mm, 75.7200 mm): PTH pad 38 [<no net>] of U1
[silk_over_copper]: Silkscreen clipped by solder mask
    Local override; warning
    @(32.1900 mm, 67.9440 mm): Segment of C2 on F.Silkscreen
    @(32.5400 mm, 68.1000 mm): PTH pad 32 [<no net>] of U1
[silk_over_copper]: Silkscreen clipped by solder mask
    Local override; warning
    @(32.1900 mm, 67.9440 mm): Segment of C2 on F.Silkscreen
    @(32.5400 mm, 70.6400 mm): PTH pad 34 [<no net>] of U1
[silk_over_copper]: Silkscreen clipped by solder mask
    Local override; warning
    @(32.1900 mm, 67.9440 mm): Segment of C2 on F.Silkscreen
    @(32.5400 mm, 73.1800 mm): PTH pad 36 [<no net>] of U1
[silk_over_copper]: Silkscreen clipped by solder mask
    Local override; warning
    @(32.1900 mm, 67.9440 mm): Segment of C2 on F.Silkscreen
    @(32.5400 mm, 75.7200 mm): PTH pad 38 [<no net>] of U1
[silk_over_copper]: Silkscreen clipped by solder mask
    Local override; warning
    @(32.2300 mm, 67.9480 mm): Segment of C2 on F.Silkscreen
    @(32.5400 mm, 68.1000 mm): PTH pad 32 [<no net>] of U1
[silk_over_copper]: Silkscreen clipped by solder mask
    Local override; warning
    @(32.2300 mm, 67.9480 mm): Segment of C2 on F.Silkscreen
    @(32.5400 mm, 70.6400 mm): PTH pad 34 [<no net>] of U1
[silk_over_copper]: Silkscreen clipped by solder mask
    Local override; warning
    @(32.2300 mm, 67.9480 mm): Segment of C2 on F.Silkscreen
    @(32.5400 mm, 73.1800 mm): PTH pad 36 [<no net>] of U1
[silk_over_copper]: Silkscreen clipped by solder mask
    Local override; warning
    @(32.2300 mm, 67.9480 mm): Segment of C2 on F.Silkscreen
    @(32.5400 mm, 75.7200 mm): PTH pad 38 [<no net>] of U1
[silk_over_copper]: Silkscreen clipped by solder mask
    Local override; warning
    @(32.3100 mm, 67.9580 mm): Segment of C2 on F.Silkscreen
    @(32.5400 mm, 68.1000 mm): PTH pad 32 [<no net>] of U1
[silk_over_copper]: Silkscreen clipped by solder mask
    Local override; warning
    @(32.3100 mm, 67.9580 mm): Segment of C2 on F.Silkscreen
    @(32.5400 mm, 70.6400 mm): PTH pad 34 [<no net>] of U1
[silk_over_copper]: Silkscreen clipped by solder mask
    Local override; warning
    @(32.3100 mm, 67.9580 mm): Segment of C2 on F.Silkscreen
    @(32.5400 mm, 73.1800 mm): PTH pad 36 [<no net>] of U1
[silk_over_copper]: Silkscreen clipped by solder mask
    Local override; warning
    @(32.3100 mm, 67.9580 mm): Segment of C2 on F.Silkscreen
    @(32.5400 mm, 75.7200 mm): PTH pad 38 [<no net>] of U1
[silk_over_copper]: Silkscreen clipped by solder mask
    Local override; warning
    @(32.3500 mm, 67.9640 mm): Segment of C2 on F.Silkscreen
    @(32.5400 mm, 68.1000 mm): PTH pad 32 [<no net>] of U1
[silk_over_copper]: Silkscreen clipped by solder mask
    Local override; warning
    @(32.3500 mm, 67.9640 mm): Segment of C2 on F.Silkscreen
    @(32.5400 mm, 70.6400 mm): PTH pad 34 [<no net>] of U1
[silk_over_copper]: Silkscreen clipped by solder mask
    Local override; warning
    @(32.3500 mm, 67.9640 mm): Segment of C2 on F.Silkscreen
    @(32.5400 mm, 73.1800 mm): PTH pad 36 [<no net>] of U1
[silk_over_copper]: Silkscreen clipped by solder mask
    Local override; warning
    @(32.3500 mm, 67.9640 mm): Segment of C2 on F.Silkscreen
    @(32.5400 mm, 75.7200 mm): PTH pad 38 [<no net>] of U1
[silk_over_copper]: Silkscreen clipped by solder mask
    Local override; warning
    @(32.3900 mm, 67.9700 mm): Segment of C2 on F.Silkscreen
    @(32.5400 mm, 68.1000 mm): PTH pad 32 [<no net>] of U1
[silk_over_copper]: Silkscreen clipped by solder mask
    Local override; warning
    @(32.3900 mm, 67.9700 mm): Segment of C2 on F.Silkscreen
    @(32.5400 mm, 70.6400 mm): PTH pad 34 [<no net>] of U1
[silk_over_copper]: Silkscreen clipped by solder mask
    Local override; warning
    @(32.3900 mm, 67.9700 mm): Segment of C2 on F.Silkscreen
    @(32.5400 mm, 73.1800 mm): PTH pad 36 [<no net>] of U1
[silk_over_copper]: Silkscreen clipped by solder mask
    Local override; warning
    @(32.3900 mm, 67.9700 mm): Segment of C2 on F.Silkscreen
    @(32.5400 mm, 75.7200 mm): PTH pad 38 [<no net>] of U1
[silk_over_copper]: Silkscreen clipped by solder mask
    Local override; warning
    @(32.4300 mm, 67.9770 mm): Segment of C2 on F.Silkscreen
    @(32.5400 mm, 68.1000 mm): PTH pad 32 [<no net>] of U1
[silk_over_copper]: Silkscreen clipped by solder mask
    Local override; warning
    @(32.4300 mm, 67.9770 mm): Segment of C2 on F.Silkscreen
    @(32.5400 mm, 70.6400 mm): PTH pad 34 [<no net>] of U1
[silk_over_copper]: Silkscreen clipped by solder mask
    Local override; warning
    @(32.4300 mm, 67.9770 mm): Segment of C2 on F.Silkscreen
    @(32.5400 mm, 73.1800 mm): PTH pad 36 [<no net>] of U1
[silk_over_copper]: Silkscreen clipped by solder mask
    Local override; warning
    @(32.4300 mm, 67.9770 mm): Segment of C2 on F.Silkscreen
    @(32.5400 mm, 75.7200 mm): PTH pad 38 [<no net>] of U1
[silk_over_copper]: Silkscreen clipped by solder mask
    Local override; warning
    @(32.4700 mm, 67.9830 mm): Segment of C2 on F.Silkscreen
    @(32.5400 mm, 68.1000 mm): PTH pad 32 [<no net>] of U1
[silk_over_copper]: Silkscreen clipped by solder mask
    Local override; warning
    @(32.4700 mm, 67.9830 mm): Segment of C2 on F.Silkscreen
    @(32.5400 mm, 70.6400 mm): PTH pad 34 [<no net>] of U1
[silk_over_copper]: Silkscreen clipped by solder mask
    Local override; warning
    @(32.4700 mm, 73.0400 mm): Segment of C2 on F.Silkscreen
    @(32.5400 mm, 73.1800 mm): PTH pad 36 [<no net>] of U1
[silk_over_copper]: Silkscreen clipped by solder mask
    Local override; warning
    @(32.4700 mm, 73.0400 mm): Segment of C2 on F.Silkscreen
    @(32.5400 mm, 75.7200 mm): PTH pad 38 [<no net>] of U1
[silk_over_copper]: Silkscreen clipped by solder mask
    Local override; warning
    @(32.2700 mm, 67.9530 mm): Segment of C2 on F.Silkscreen
    @(32.5400 mm, 68.1000 mm): PTH pad 32 [<no net>] of U1
[silk_over_copper]: Silkscreen clipped by solder mask
    Local override; warning
    @(32.2700 mm, 67.9530 mm): Segment of C2 on F.Silkscreen
    @(32.5400 mm, 70.6400 mm): PTH pad 34 [<no net>] of U1
[silk_over_copper]: Silkscreen clipped by solder mask
    Local override; warning
    @(32.2700 mm, 67.9530 mm): Segment of C2 on F.Silkscreen
    @(32.5400 mm, 73.1800 mm): PTH pad 36 [<no net>] of U1
[silk_over_copper]: Silkscreen clipped by solder mask
    Local override; warning
    @(32.2700 mm, 67.9530 mm): Segment of C2 on F.Silkscreen
    @(32.5400 mm, 75.7200 mm): PTH pad 38 [<no net>] of U1
[silk_over_copper]: Silkscreen clipped by solder mask
    Local override; warning
    @(32.5100 mm, 67.9910 mm): Segment of C2 on F.Silkscreen
    @(32.5400 mm, 68.1000 mm): PTH pad 32 [<no net>] of U1
[silk_over_copper]: Silkscreen clipped by solder mask
    Local override; warning
    @(32.5100 mm, 67.9910 mm): Segment of C2 on F.Silkscreen
    @(32.5400 mm, 70.6400 mm): PTH pad 34 [<no net>] of U1
[silk_over_copper]: Silkscreen clipped by solder mask
    Local override; warning
    @(32.5100 mm, 73.0400 mm): Segment of C2 on F.Silkscreen
    @(32.5400 mm, 73.1800 mm): PTH pad 36 [<no net>] of U1
[silk_over_copper]: Silkscreen clipped by solder mask
    Local override; warning
    @(32.5100 mm, 73.0400 mm): Segment of C2 on F.Silkscreen
    @(32.5400 mm, 75.7200 mm): PTH pad 38 [<no net>] of U1
[silk_over_copper]: Silkscreen clipped by solder mask
    Local override; warning
    @(32.5500 mm, 67.9980 mm): Segment of C2 on F.Silkscreen
    @(32.5400 mm, 68.1000 mm): PTH pad 32 [<no net>] of U1
[silk_over_copper]: Silkscreen clipped by solder mask
    Local override; warning
    @(32.5500 mm, 67.9980 mm): Segment of C2 on F.Silkscreen
    @(32.5400 mm, 70.6400 mm): PTH pad 34 [<no net>] of U1
[silk_over_copper]: Silkscreen clipped by solder mask
    Local override; warning
    @(32.5900 mm, 68.0070 mm): Segment of C2 on F.Silkscreen
    @(32.5400 mm, 68.1000 mm): PTH pad 32 [<no net>] of U1
[silk_over_copper]: Silkscreen clipped by solder mask
    Local override; warning
    @(32.5900 mm, 68.0070 mm): Segment of C2 on F.Silkscreen
    @(32.5400 mm, 70.6400 mm): PTH pad 34 [<no net>] of U1
[silk_over_copper]: Silkscreen clipped by solder mask
    Local override; warning
    @(32.5900 mm, 73.0400 mm): Segment of C2 on F.Silkscreen
    @(32.5400 mm, 73.1800 mm): PTH pad 36 [<no net>] of U1
[silk_over_copper]: Silkscreen clipped by solder mask
    Local override; warning
    @(32.5900 mm, 73.0400 mm): Segment of C2 on F.Silkscreen
    @(32.5400 mm, 75.7200 mm): PTH pad 38 [<no net>] of U1
[silk_over_copper]: Silkscreen clipped by solder mask
    Local override; warning
    @(32.6300 mm, 68.0150 mm): Segment of C2 on F.Silkscreen
    @(32.5400 mm, 68.1000 mm): PTH pad 32 [<no net>] of U1
[silk_over_copper]: Silkscreen clipped by solder mask
    Local override; warning
    @(32.6300 mm, 68.0150 mm): Segment of C2 on F.Silkscreen
    @(32.5400 mm, 70.6400 mm): PTH pad 34 [<no net>] of U1
[silk_over_copper]: Silkscreen clipped by solder mask
    Local override; warning
    @(32.6300 mm, 73.0400 mm): Segment of C2 on F.Silkscreen
    @(32.5400 mm, 73.1800 mm): PTH pad 36 [<no net>] of U1
[silk_over_copper]: Silkscreen clipped by solder mask
    Local override; warning
    @(32.6300 mm, 73.0400 mm): Segment of C2 on F.Silkscreen
    @(32.5400 mm, 75.7200 mm): PTH pad 38 [<no net>] of U1
[silk_over_copper]: Silkscreen clipped by solder mask
    Local override; warning
    @(32.6700 mm, 68.0240 mm): Segment of C2 on F.Silkscreen
    @(32.5400 mm, 68.1000 mm): PTH pad 32 [<no net>] of U1
[silk_over_copper]: Silkscreen clipped by solder mask
    Local override; warning
    @(32.6700 mm, 68.0240 mm): Segment of C2 on F.Silkscreen
    @(32.5400 mm, 70.6400 mm): PTH pad 34 [<no net>] of U1
[silk_over_copper]: Silkscreen clipped by solder mask
    Local override; warning
    @(32.6700 mm, 73.0400 mm): Segment of C2 on F.Silkscreen
    @(32.5400 mm, 73.1800 mm): PTH pad 36 [<no net>] of U1
[silk_over_copper]: Silkscreen clipped by solder mask
    Local override; warning
    @(32.6700 mm, 73.0400 mm): Segment of C2 on F.Silkscreen
    @(32.5400 mm, 75.7200 mm): PTH pad 38 [<no net>] of U1
[silk_over_copper]: Silkscreen clipped by solder mask
    Local override; warning
    @(32.7100 mm, 68.0330 mm): Segment of C2 on F.Silkscreen
    @(32.5400 mm, 68.1000 mm): PTH pad 32 [<no net>] of U1
[silk_over_copper]: Silkscreen clipped by solder mask
    Local override; warning
    @(32.7100 mm, 68.0330 mm): Segment of C2 on F.Silkscreen
    @(32.5400 mm, 70.6400 mm): PTH pad 34 [<no net>] of U1
[silk_over_copper]: Silkscreen clipped by solder mask
    Local override; warning
    @(32.7100 mm, 73.0400 mm): Segment of C2 on F.Silkscreen
    @(32.5400 mm, 73.1800 mm): PTH pad 36 [<no net>] of U1
[silk_over_copper]: Silkscreen clipped by solder mask
    Local override; warning
    @(32.7100 mm, 73.0400 mm): Segment of C2 on F.Silkscreen
    @(32.5400 mm, 75.7200 mm): PTH pad 38 [<no net>] of U1
[silk_over_copper]: Silkscreen clipped by solder mask
    Local override; warning
    @(32.7500 mm, 68.0430 mm): Segment of C2 on F.Silkscreen
    @(32.5400 mm, 68.1000 mm): PTH pad 32 [<no net>] of U1
[silk_over_copper]: Silkscreen clipped by solder mask
    Local override; warning
    @(32.7500 mm, 68.0430 mm): Segment of C2 on F.Silkscreen
    @(32.5400 mm, 70.6400 mm): PTH pad 34 [<no net>] of U1
[silk_over_copper]: Silkscreen clipped by solder mask
    Local override; warning
    @(32.7500 mm, 73.0400 mm): Segment of C2 on F.Silkscreen
    @(32.5400 mm, 73.1800 mm): PTH pad 36 [<no net>] of U1
[silk_over_copper]: Silkscreen clipped by solder mask
    Local override; warning
    @(32.7500 mm, 73.0400 mm): Segment of C2 on F.Silkscreen
    @(32.5400 mm, 75.7200 mm): PTH pad 38 [<no net>] of U1
[silk_over_copper]: Silkscreen clipped by solder mask
    Local override; warning
    @(32.7900 mm, 68.0530 mm): Segment of C2 on F.Silkscreen
    @(32.5400 mm, 68.1000 mm): PTH pad 32 [<no net>] of U1
[silk_over_copper]: Silkscreen clipped by solder mask
    Local override; warning
    @(32.7900 mm, 68.0530 mm): Segment of C2 on F.Silkscreen
    @(32.5400 mm, 70.6400 mm): PTH pad 34 [<no net>] of U1
[silk_over_copper]: Silkscreen clipped by solder mask
    Local override; warning
    @(32.7900 mm, 73.0400 mm): Segment of C2 on F.Silkscreen
    @(32.5400 mm, 73.1800 mm): PTH pad 36 [<no net>] of U1
[silk_over_copper]: Silkscreen clipped by solder mask
    Local override; warning
    @(32.7900 mm, 73.0400 mm): Segment of C2 on F.Silkscreen
    @(32.5400 mm, 75.7200 mm): PTH pad 38 [<no net>] of U1
[silk_over_copper]: Silkscreen clipped by solder mask
    Local override; warning
    @(32.8300 mm, 68.0640 mm): Segment of C2 on F.Silkscreen
    @(32.5400 mm, 68.1000 mm): PTH pad 32 [<no net>] of U1
[silk_over_copper]: Silkscreen clipped by solder mask
    Local override; warning
    @(32.8300 mm, 68.0640 mm): Segment of C2 on F.Silkscreen
    @(32.5400 mm, 70.6400 mm): PTH pad 34 [<no net>] of U1
[silk_over_copper]: Silkscreen clipped by solder mask
    Local override; warning
    @(32.8300 mm, 73.0400 mm): Segment of C2 on F.Silkscreen
    @(32.5400 mm, 73.1800 mm): PTH pad 36 [<no net>] of U1
[silk_over_copper]: Silkscreen clipped by solder mask
    Local override; warning
    @(32.8300 mm, 73.0400 mm): Segment of C2 on F.Silkscreen
    @(32.5400 mm, 75.7200 mm): PTH pad 38 [<no net>] of U1
[silk_over_copper]: Silkscreen clipped by solder mask
    Local override; warning
    @(31.8700 mm, 67.9220 mm): Segment of C2 on F.Silkscreen
    @(32.5400 mm, 68.1000 mm): PTH pad 32 [<no net>] of U1
[silk_over_copper]: Silkscreen clipped by solder mask
    Local override; warning
    @(31.8700 mm, 67.9220 mm): Segment of C2 on F.Silkscreen
    @(32.5400 mm, 70.6400 mm): PTH pad 34 [<no net>] of U1
[silk_over_copper]: Silkscreen clipped by solder mask
    Local override; warning
    @(31.8700 mm, 67.9220 mm): Segment of C2 on F.Silkscreen
    @(32.5400 mm, 73.1800 mm): PTH pad 36 [<no net>] of U1
[silk_over_copper]: Silkscreen clipped by solder mask
    Local override; warning
    @(31.8700 mm, 67.9220 mm): Segment of C2 on F.Silkscreen
    @(32.5400 mm, 75.7200 mm): PTH pad 38 [<no net>] of U1
[silk_over_copper]: Silkscreen clipped by solder mask
    Local override; warning
    @(31.9100 mm, 67.9230 mm): Segment of C2 on F.Silkscreen
    @(32.5400 mm, 68.1000 mm): PTH pad 32 [<no net>] of U1
[silk_over_copper]: Silkscreen clipped by solder mask
    Local override; warning
    @(31.9100 mm, 67.9230 mm): Segment of C2 on F.Silkscreen
    @(32.5400 mm, 70.6400 mm): PTH pad 34 [<no net>] of U1
[silk_over_copper]: Silkscreen clipped by solder mask
    Local override; warning
    @(31.9100 mm, 67.9230 mm): Segment of C2 on F.Silkscreen
    @(32.5400 mm, 73.1800 mm): PTH pad 36 [<no net>] of U1
[silk_over_copper]: Silkscreen clipped by solder mask
    Local override; warning
    @(31.9100 mm, 67.9230 mm): Segment of C2 on F.Silkscreen
    @(32.5400 mm, 75.7200 mm): PTH pad 38 [<no net>] of U1
[silk_over_copper]: Silkscreen clipped by solder mask
    Local override; warning
    @(31.9500 mm, 67.9250 mm): Segment of C2 on F.Silkscreen
    @(32.5400 mm, 68.1000 mm): PTH pad 32 [<no net>] of U1
[silk_over_copper]: Silkscreen clipped by solder mask
    Local override; warning
    @(31.9500 mm, 67.9250 mm): Segment of C2 on F.Silkscreen
    @(32.5400 mm, 70.6400 mm): PTH pad 34 [<no net>] of U1
[silk_over_copper]: Silkscreen clipped by solder mask
    Local override; warning
    @(31.9500 mm, 67.9250 mm): Segment of C2 on F.Silkscreen
    @(32.5400 mm, 73.1800 mm): PTH pad 36 [<no net>] of U1
[silk_over_copper]: Silkscreen clipped by solder mask
    Local override; warning
    @(31.9500 mm, 67.9250 mm): Segment of C2 on F.Silkscreen
    @(32.5400 mm, 75.7200 mm): PTH pad 38 [<no net>] of U1
[silk_over_copper]: Silkscreen clipped by solder mask
    Local override; warning
    @(31.9900 mm, 67.9270 mm): Segment of C2 on F.Silkscreen
    @(32.5400 mm, 68.1000 mm): PTH pad 32 [<no net>] of U1
[silk_over_copper]: Silkscreen clipped by solder mask
    Local override; warning
    @(31.9900 mm, 67.9270 mm): Segment of C2 on F.Silkscreen
    @(32.5400 mm, 70.6400 mm): PTH pad 34 [<no net>] of U1
[silk_over_copper]: Silkscreen clipped by solder mask
    Local override; warning
    @(31.9900 mm, 67.9270 mm): Segment of C2 on F.Silkscreen
    @(32.5400 mm, 73.1800 mm): PTH pad 36 [<no net>] of U1
[silk_over_copper]: Silkscreen clipped by solder mask
    Local override; warning
    @(31.9900 mm, 67.9270 mm): Segment of C2 on F.Silkscreen
    @(32.5400 mm, 75.7200 mm): PTH pad 38 [<no net>] of U1
[silk_over_copper]: Silkscreen clipped by solder mask
    Local override; warning
    @(32.0300 mm, 67.9300 mm): Segment of C2 on F.Silkscreen
    @(32.5400 mm, 68.1000 mm): PTH pad 32 [<no net>] of U1
[silk_over_copper]: Silkscreen clipped by solder mask
    Local override; warning
    @(32.0300 mm, 67.9300 mm): Segment of C2 on F.Silkscreen
    @(32.5400 mm, 70.6400 mm): PTH pad 34 [<no net>] of U1
[silk_over_copper]: Silkscreen clipped by solder mask
    Local override; warning
    @(32.0300 mm, 67.9300 mm): Segment of C2 on F.Silkscreen
    @(32.5400 mm, 73.1800 mm): PTH pad 36 [<no net>] of U1
[silk_over_copper]: Silkscreen clipped by solder mask
    Local override; warning
    @(32.0300 mm, 67.9300 mm): Segment of C2 on F.Silkscreen
    @(32.5400 mm, 75.7200 mm): PTH pad 38 [<no net>] of U1
[silk_over_copper]: Silkscreen clipped by solder mask
    Local override; warning
    @(33.2300 mm, 68.1950 mm): Segment of C2 on F.Silkscreen
    @(32.5400 mm, 68.1000 mm): PTH pad 32 [<no net>] of U1
[silk_over_copper]: Silkscreen clipped by solder mask
    Local override; warning
    @(33.2300 mm, 68.1950 mm): Segment of C2 on F.Silkscreen
    @(32.5400 mm, 70.6400 mm): PTH pad 34 [<no net>] of U1
[silk_over_copper]: Silkscreen clipped by solder mask
    Local override; warning
    @(33.2700 mm, 68.2110 mm): Segment of C2 on F.Silkscreen
    @(32.5400 mm, 68.1000 mm): PTH pad 32 [<no net>] of U1
[silk_over_copper]: Silkscreen clipped by solder mask
    Local override; warning
    @(33.2700 mm, 68.2110 mm): Segment of C2 on F.Silkscreen
    @(32.5400 mm, 70.6400 mm): PTH pad 34 [<no net>] of U1
[silk_over_copper]: Silkscreen clipped by solder mask
    Local override; warning
    @(33.3100 mm, 68.2270 mm): Segment of C2 on F.Silkscreen
    @(32.5400 mm, 68.1000 mm): PTH pad 32 [<no net>] of U1
[silk_over_copper]: Silkscreen clipped by solder mask
    Local override; warning
    @(33.3100 mm, 68.2270 mm): Segment of C2 on F.Silkscreen
    @(32.5400 mm, 70.6400 mm): PTH pad 34 [<no net>] of U1
[silk_over_copper]: Silkscreen clipped by solder mask
    Local override; warning
    @(33.3500 mm, 68.2430 mm): Segment of C2 on F.Silkscreen
    @(32.5400 mm, 68.1000 mm): PTH pad 32 [<no net>] of U1
[silk_over_copper]: Silkscreen clipped by solder mask
    Local override; warning
    @(33.3500 mm, 68.2430 mm): Segment of C2 on F.Silkscreen
    @(32.5400 mm, 70.6400 mm): PTH pad 34 [<no net>] of U1
[silk_over_copper]: Silkscreen clipped by solder mask
    Local override; warning
    @(33.3900 mm, 68.2600 mm): Segment of C2 on F.Silkscreen
    @(32.5400 mm, 68.1000 mm): PTH pad 32 [<no net>] of U1
[silk_over_copper]: Silkscreen clipped by solder mask
    Local override; warning
    @(33.3900 mm, 68.2600 mm): Segment of C2 on F.Silkscreen
    @(32.5400 mm, 70.6400 mm): PTH pad 34 [<no net>] of U1
[silk_over_copper]: Silkscreen clipped by solder mask
    Local override; warning
    @(33.4300 mm, 68.2780 mm): Segment of C2 on F.Silkscreen
    @(32.5400 mm, 68.1000 mm): PTH pad 32 [<no net>] of U1
[silk_over_copper]: Silkscreen clipped by solder mask
    Local override; warning
    @(33.4300 mm, 68.2780 mm): Segment of C2 on F.Silkscreen
    @(32.5400 mm, 70.6400 mm): PTH pad 34 [<no net>] of U1
[silk_over_copper]: Silkscreen clipped by solder mask
    Local override; warning
    @(32.8700 mm, 68.0750 mm): Segment of C2 on F.Silkscreen
    @(32.5400 mm, 68.1000 mm): PTH pad 32 [<no net>] of U1
[silk_over_copper]: Silkscreen clipped by solder mask
    Local override; warning
    @(32.8700 mm, 68.0750 mm): Segment of C2 on F.Silkscreen
    @(32.5400 mm, 70.6400 mm): PTH pad 34 [<no net>] of U1
[silk_over_copper]: Silkscreen clipped by solder mask
    Local override; warning
    @(32.8700 mm, 73.0400 mm): Segment of C2 on F.Silkscreen
    @(32.5400 mm, 73.1800 mm): PTH pad 36 [<no net>] of U1
[silk_over_copper]: Silkscreen clipped by solder mask
    Local override; warning
    @(32.8700 mm, 73.0400 mm): Segment of C2 on F.Silkscreen
    @(32.5400 mm, 75.7200 mm): PTH pad 38 [<no net>] of U1
[silk_over_copper]: Silkscreen clipped by solder mask
    Local override; warning
    @(32.9100 mm, 68.0870 mm): Segment of C2 on F.Silkscreen
    @(32.5400 mm, 68.1000 mm): PTH pad 32 [<no net>] of U1
[silk_over_copper]: Silkscreen clipped by solder mask
    Local override; warning
    @(32.9100 mm, 68.0870 mm): Segment of C2 on F.Silkscreen
    @(32.5400 mm, 70.6400 mm): PTH pad 34 [<no net>] of U1
[silk_over_copper]: Silkscreen clipped by solder mask
    Local override; warning
    @(32.9100 mm, 73.0400 mm): Segment of C2 on F.Silkscreen
    @(32.5400 mm, 73.1800 mm): PTH pad 36 [<no net>] of U1
[silk_over_copper]: Silkscreen clipped by solder mask
    Local override; warning
    @(32.9100 mm, 73.0400 mm): Segment of C2 on F.Silkscreen
    @(32.5400 mm, 75.7200 mm): PTH pad 38 [<no net>] of U1
[silk_over_copper]: Silkscreen clipped by solder mask
    Local override; warning
    @(32.9500 mm, 68.0990 mm): Segment of C2 on F.Silkscreen
    @(32.5400 mm, 68.1000 mm): PTH pad 32 [<no net>] of U1
[silk_over_copper]: Silkscreen clipped by solder mask
    Local override; warning
    @(32.9500 mm, 68.0990 mm): Segment of C2 on F.Silkscreen
    @(32.5400 mm, 70.6400 mm): PTH pad 34 [<no net>] of U1
[silk_over_copper]: Silkscreen clipped by solder mask
    Local override; warning
    @(32.9500 mm, 73.0400 mm): Segment of C2 on F.Silkscreen
    @(32.5400 mm, 73.1800 mm): PTH pad 36 [<no net>] of U1
[silk_over_copper]: Silkscreen clipped by solder mask
    Local override; warning
    @(32.9500 mm, 73.0400 mm): Segment of C2 on F.Silkscreen
    @(32.5400 mm, 75.7200 mm): PTH pad 38 [<no net>] of U1
[silk_over_copper]: Silkscreen clipped by solder mask
    Local override; warning
    @(32.9900 mm, 68.1110 mm): Segment of C2 on F.Silkscreen
    @(32.5400 mm, 68.1000 mm): PTH pad 32 [<no net>] of U1
[silk_over_copper]: Silkscreen clipped by solder mask
    Local override; warning
    @(32.9900 mm, 68.1110 mm): Segment of C2 on F.Silkscreen
    @(32.5400 mm, 70.6400 mm): PTH pad 34 [<no net>] of U1
[silk_over_copper]: Silkscreen clipped by solder mask
    Local override; warning
    @(32.9900 mm, 73.0400 mm): Segment of C2 on F.Silkscreen
    @(32.5400 mm, 73.1800 mm): PTH pad 36 [<no net>] of U1
[silk_over_copper]: Silkscreen clipped by solder mask
    Local override; warning
    @(32.9900 mm, 73.0400 mm): Segment of C2 on F.Silkscreen
    @(32.5400 mm, 75.7200 mm): PTH pad 38 [<no net>] of U1
[silk_over_copper]: Silkscreen clipped by solder mask
    Local override; warning
    @(33.0300 mm, 68.1240 mm): Segment of C2 on F.Silkscreen
    @(32.5400 mm, 68.1000 mm): PTH pad 32 [<no net>] of U1
[silk_over_copper]: Silkscreen clipped by solder mask
    Local override; warning
    @(33.0300 mm, 68.1240 mm): Segment of C2 on F.Silkscreen
    @(32.5400 mm, 70.6400 mm): PTH pad 34 [<no net>] of U1
[silk_over_copper]: Silkscreen clipped by solder mask
    Local override; warning
    @(33.0300 mm, 73.0400 mm): Segment of C2 on F.Silkscreen
    @(32.5400 mm, 73.1800 mm): PTH pad 36 [<no net>] of U1
[silk_over_copper]: Silkscreen clipped by solder mask
    Local override; warning
    @(33.0300 mm, 73.0400 mm): Segment of C2 on F.Silkscreen
    @(32.5400 mm, 75.7200 mm): PTH pad 38 [<no net>] of U1
[silk_over_copper]: Silkscreen clipped by solder mask
    Local override; warning
    @(33.0700 mm, 68.1370 mm): Segment of C2 on F.Silkscreen
    @(32.5400 mm, 68.1000 mm): PTH pad 32 [<no net>] of U1
[silk_over_copper]: Silkscreen clipped by solder mask
    Local override; warning
    @(33.0700 mm, 68.1370 mm): Segment of C2 on F.Silkscreen
    @(32.5400 mm, 70.6400 mm): PTH pad 34 [<no net>] of U1
[silk_over_copper]: Silkscreen clipped by solder mask
    Local override; warning
    @(33.0700 mm, 73.0400 mm): Segment of C2 on F.Silkscreen
    @(32.5400 mm, 73.1800 mm): PTH pad 36 [<no net>] of U1
[silk_over_copper]: Silkscreen clipped by solder mask
    Local override; warning
    @(33.0700 mm, 73.0400 mm): Segment of C2 on F.Silkscreen
    @(32.5400 mm, 75.7200 mm): PTH pad 38 [<no net>] of U1
[silk_over_copper]: Silkscreen clipped by solder mask
    Local override; warning
    @(33.1100 mm, 68.1510 mm): Segment of C2 on F.Silkscreen
    @(32.5400 mm, 68.1000 mm): PTH pad 32 [<no net>] of U1
[silk_over_copper]: Silkscreen clipped by solder mask
    Local override; warning
    @(33.1100 mm, 68.1510 mm): Segment of C2 on F.Silkscreen
    @(32.5400 mm, 70.6400 mm): PTH pad 34 [<no net>] of U1
[silk_over_copper]: Silkscreen clipped by solder mask
    Local override; warning
    @(33.1100 mm, 73.0400 mm): Segment of C2 on F.Silkscreen
    @(32.5400 mm, 73.1800 mm): PTH pad 36 [<no net>] of U1
[silk_over_copper]: Silkscreen clipped by solder mask
    Local override; warning
    @(33.1100 mm, 73.0400 mm): Segment of C2 on F.Silkscreen
    @(32.5400 mm, 75.7200 mm): PTH pad 38 [<no net>] of U1
[silk_over_copper]: Silkscreen clipped by solder mask
    Local override; warning
    @(33.1500 mm, 68.1650 mm): Segment of C2 on F.Silkscreen
    @(32.5400 mm, 68.1000 mm): PTH pad 32 [<no net>] of U1
[silk_over_copper]: Silkscreen clipped by solder mask
    Local override; warning
    @(33.1500 mm, 68.1650 mm): Segment of C2 on F.Silkscreen
    @(32.5400 mm, 70.6400 mm): PTH pad 34 [<no net>] of U1
[silk_over_copper]: Silkscreen clipped by solder mask
    Local override; warning
    @(33.1500 mm, 73.0400 mm): Segment of C2 on F.Silkscreen
    @(32.5400 mm, 73.1800 mm): PTH pad 36 [<no net>] of U1
[silk_over_copper]: Silkscreen clipped by solder mask
    Local override; warning
    @(33.1500 mm, 73.0400 mm): Segment of C2 on F.Silkscreen
    @(32.5400 mm, 75.7200 mm): PTH pad 38 [<no net>] of U1
[silk_over_copper]: Silkscreen clipped by solder mask
    Local override; warning
    @(33.1900 mm, 68.1800 mm): Segment of C2 on F.Silkscreen
    @(32.5400 mm, 68.1000 mm): PTH pad 32 [<no net>] of U1
[silk_over_copper]: Silkscreen clipped by solder mask
    Local override; warning
    @(33.1900 mm, 68.1800 mm): Segment of C2 on F.Silkscreen
    @(32.5400 mm, 70.6400 mm): PTH pad 34 [<no net>] of U1
[silk_over_copper]: Silkscreen clipped by solder mask
    Local override; warning
    @(33.1900 mm, 73.0400 mm): Segment of C2 on F.Silkscreen
    @(32.5400 mm, 73.1800 mm): PTH pad 36 [<no net>] of U1
[silk_over_copper]: Silkscreen clipped by solder mask
    Local override; warning
    @(33.1900 mm, 73.0400 mm): Segment of C2 on F.Silkscreen
    @(32.5400 mm, 75.7200 mm): PTH pad 38 [<no net>] of U1
[silk_over_copper]: Silkscreen clipped by solder mask
    Local override; warning
    @(33.3500 mm, 73.0400 mm): Segment of C2 on F.Silkscreen
    @(32.5400 mm, 73.1800 mm): PTH pad 36 [<no net>] of U1
[silk_over_copper]: Silkscreen clipped by solder mask
    Local override; warning
    @(33.3500 mm, 73.0400 mm): Segment of C2 on F.Silkscreen
    @(32.5400 mm, 75.7200 mm): PTH pad 38 [<no net>] of U1
[silk_over_copper]: Silkscreen clipped by solder mask
    Local override; warning
    @(33.3900 mm, 73.0400 mm): Segment of C2 on F.Silkscreen
    @(32.5400 mm, 73.1800 mm): PTH pad 36 [<no net>] of U1
[silk_over_copper]: Silkscreen clipped by solder mask
    Local override; warning
    @(33.3900 mm, 73.0400 mm): Segment of C2 on F.Silkscreen
    @(32.5400 mm, 75.7200 mm): PTH pad 38 [<no net>] of U1
[silk_over_copper]: Silkscreen clipped by solder mask
    Local override; warning
    @(33.4300 mm, 73.0400 mm): Segment of C2 on F.Silkscreen
    @(32.5400 mm, 73.1800 mm): PTH pad 36 [<no net>] of U1
[silk_over_copper]: Silkscreen clipped by solder mask
    Local override; warning
    @(33.4300 mm, 73.0400 mm): Segment of C2 on F.Silkscreen
    @(32.5400 mm, 75.7200 mm): PTH pad 38 [<no net>] of U1
[silk_over_copper]: Silkscreen clipped by solder mask
    Local override; warning
    @(33.2300 mm, 73.0400 mm): Segment of C2 on F.Silkscreen
    @(32.5400 mm, 73.1800 mm): PTH pad 36 [<no net>] of U1
[silk_over_copper]: Silkscreen clipped by solder mask
    Local override; warning
    @(33.2300 mm, 73.0400 mm): Segment of C2 on F.Silkscreen
    @(32.5400 mm, 75.7200 mm): PTH pad 38 [<no net>] of U1
[silk_over_copper]: Silkscreen clipped by solder mask
    Local override; warning
    @(33.2700 mm, 73.0400 mm): Segment of C2 on F.Silkscreen
    @(32.5400 mm, 73.1800 mm): PTH pad 36 [<no net>] of U1
[silk_over_copper]: Silkscreen clipped by solder mask
    Local override; warning
    @(33.2700 mm, 73.0400 mm): Segment of C2 on F.Silkscreen
    @(32.5400 mm, 75.7200 mm): PTH pad 38 [<no net>] of U1
[silk_over_copper]: Silkscreen clipped by solder mask
    Local override; warning
    @(33.3100 mm, 73.0400 mm): Segment of C2 on F.Silkscreen
    @(32.5400 mm, 73.1800 mm): PTH pad 36 [<no net>] of U1
[silk_over_copper]: Silkscreen clipped by solder mask
    Local override; warning
    @(33.3100 mm, 73.0400 mm): Segment of C2 on F.Silkscreen
    @(32.5400 mm, 75.7200 mm): PTH pad 38 [<no net>] of U1

** Found 104 unconnected pads **
[unconnected_items]: Missing connection between items
    Local override; error
    @(32.5400 mm, 42.7000 mm): PTH pad 12 [LED_PWM] of U1
    @(239.0875 mm, 156.0000 mm): Pad 1 [LED_PWM] of R3 on F.Cu
[unconnected_items]: Missing connection between items
    Local override; error
    @(199.2700 mm, 156.0000 mm): PTH pad 2 [LED_GATE] of Q1
    @(29.0875 mm, 198.0000 mm): Pad 1 [LED_GATE] of R4 on F.Cu
[unconnected_items]: Missing connection between items
    Local override; error
    @(240.9125 mm, 156.0000 mm): Pad 2 [LED_GATE] of R3 on F.Cu
    @(199.2700 mm, 156.0000 mm): PTH pad 2 [LED_GATE] of Q1
[unconnected_items]: Missing connection between items
    Local override; error
    @(30.0000 mm, 30.0000 mm): PTH pad 1 [+5V] of U1
    @(30.0000 mm, 72.0000 mm): PTH pad 1 [+5V] of C2
[unconnected_items]: Missing connection between items
    Local override; error
    @(72.0000 mm, 198.0000 mm): PTH pad 1 [+5V] of D2
    @(116.5400 mm, 156.0000 mm): PTH pad 2 [+5V] of D1
[unconnected_items]: Missing connection between items
    Local override; error
    @(116.5400 mm, 156.0000 mm): PTH pad 2 [+5V] of D1
    @(198.0000 mm, 114.0000 mm): PTH pad 1 [+5V] of U9
[unconnected_items]: Missing connection between items
    Local override; error
    @(116.5400 mm, 156.0000 mm): PTH pad 2 [+5V] of D1
    @(30.0000 mm, 72.0000 mm): PTH pad 1 [+5V] of C2
[unconnected_items]: Missing connection between items
    Local override; error
    @(156.0000 mm, 37.6200 mm): PTH pad 4 [+5V] of U3
    @(156.0000 mm, 35.0800 mm): PTH pad 3 [+5V] of U3
[unconnected_items]: Missing connection between items
    Local override; error
    @(194.8500 mm, 32.3000 mm): Pad 3 [+5V] of U12 on F.Cu
    @(156.0000 mm, 35.0800 mm): PTH pad 3 [+5V] of U3
[unconnected_items]: Missing connection between items
    Local override; error
    @(194.8500 mm, 32.3000 mm): Pad 3 [+5V] of U12 on F.Cu
    @(198.0000 mm, 114.0000 mm): PTH pad 1 [+5V] of U9
[unconnected_items]: Missing connection between items
    Local override; error
    @(198.0000 mm, 198.0000 mm): PTH pad 1 [+5V] of PR1
    @(240.0000 mm, 198.0000 mm): PTH pad 1 [+5V] of LCD1
[unconnected_items]: Missing connection between items
    Local override; error
    @(198.0000 mm, 198.0000 mm): PTH pad 1 [+5V] of PR1
    @(198.0000 mm, 114.0000 mm): PTH pad 1 [+5V] of U9
[unconnected_items]: Missing connection between items
    Local override; error
    @(240.0000 mm, 30.0000 mm): PTH pad 1 [+5V] of C1
    @(194.8500 mm, 32.3000 mm): Pad 3 [+5V] of U12 on F.Cu
[unconnected_items]: Missing connection between items
    Local override; error
    @(30.0000 mm, 32.5400 mm): PTH pad 3 [GND] of U1
    @(33.5000 mm, 72.0000 mm): PTH pad 2 [GND] of C2
[unconnected_items]: Missing connection between items
    Local override; error
    @(30.0000 mm, 116.5400 mm): PTH pad 2 [GND] of U7
    @(30.0000 mm, 124.1600 mm): PTH pad 5 [GND] of U7
[unconnected_items]: Missing connection between items
    Local override; error
    @(30.0000 mm, 124.1600 mm): PTH pad 5 [GND] of U7
    @(30.0000 mm, 156.0000 mm): PTH pad 1 [GND] of SW1
[unconnected_items]: Missing connection between items
    Local override; error
    @(30.0000 mm, 124.1600 mm): PTH pad 5 [GND] of U7
    @(72.0000 mm, 124.1600 mm): PTH pad 5 [GND] of U8
[unconnected_items]: Missing connection between items
    Local override; error
    @(30.0000 mm, 242.5400 mm): PTH pad 2 [GND] of SW3
    @(30.9125 mm, 198.0000 mm): Pad 2 [GND] of R4 on F.Cu
[unconnected_items]: Missing connection between items
    Local override; error
    @(30.9125 mm, 198.0000 mm): Pad 2 [GND] of R4 on F.Cu
    @(30.0000 mm, 156.0000 mm): PTH pad 1 [GND] of SW1
[unconnected_items]: Missing connection between items
    Local override; error
    @(32.5400 mm, 30.0000 mm): PTH pad 2 [GND] of U1
    @(30.0000 mm, 32.5400 mm): PTH pad 3 [GND] of U1
[unconnected_items]: Missing connection between items
    Local override; error
    @(33.5000 mm, 72.0000 mm): PTH pad 2 [GND] of C2
    @(72.9500 mm, 72.0000 mm): Pad 2 [GND] of C3 on F.Cu
[unconnected_items]: Missing connection between items
    Local override; error
    @(72.0000 mm, 124.1600 mm): PTH pad 5 [GND] of U8
    @(72.0000 mm, 116.5400 mm): PTH pad 2 [GND] of U8
[unconnected_items]: Missing connection between items
    Local override; error
    @(72.0000 mm, 124.1600 mm): PTH pad 5 [GND] of U8
    @(72.0000 mm, 156.0000 mm): PTH pad 1 [GND] of SW2
[unconnected_items]: Missing connection between items
    Local override; error
    @(72.0000 mm, 200.5400 mm): PTH pad 2 [GND] of D2
    @(30.9125 mm, 198.0000 mm): Pad 2 [GND] of R4 on F.Cu
[unconnected_items]: Missing connection between items
    Local override; error
    @(72.9500 mm, 72.0000 mm): Pad 2 [GND] of C3 on F.Cu
    @(114.0000 mm, 74.5400 mm): PTH pad 2 [GND] of U11
[unconnected_items]: Missing connection between items
    Local override; error
    @(74.0000 mm, 30.0000 mm): PTH pad 2 [GND] of BT1
    @(114.0000 mm, 32.5400 mm): PTH pad 2 [GND] of U2
[unconnected_items]: Missing connection between items
    Local override; error
    @(114.0000 mm, 37.6200 mm): PTH pad 4 [GND] of U2
    @(114.0000 mm, 32.5400 mm): PTH pad 2 [GND] of U2
[unconnected_items]: Missing connection between items
    Local override; error
    @(114.0000 mm, 42.7000 mm): PTH pad 6 [GND] of U2
    @(114.0000 mm, 37.6200 mm): PTH pad 4 [GND] of U2
[unconnected_items]: Missing connection between items
    Local override; error
    @(114.0000 mm, 42.7000 mm): PTH pad 6 [GND] of U2
    @(114.0000 mm, 74.5400 mm): PTH pad 2 [GND] of U11
[unconnected_items]: Missing connection between items
    Local override; error
    @(114.0000 mm, 84.7000 mm): PTH pad 6 [GND] of U11
    @(114.0000 mm, 87.2400 mm): PTH pad 7 [GND] of U11
[unconnected_items]: Missing connection between items
    Local override; error
    @(114.0000 mm, 84.7000 mm): PTH pad 6 [GND] of U11
    @(114.0000 mm, 74.5400 mm): PTH pad 2 [GND] of U11
[unconnected_items]: Missing connection between items
    Local override; error
    @(114.0000 mm, 89.7800 mm): PTH pad 8 [GND] of U11
    @(114.0000 mm, 87.2400 mm): PTH pad 7 [GND] of U11
[unconnected_items]: Missing connection between items
    Local override; error
    @(114.9125 mm, 198.0000 mm): Pad 2 [GND] of R5 on F.Cu
    @(156.0000 mm, 200.5400 mm): PTH pad 2 [GND] of U10
[unconnected_items]: Missing connection between items
    Local override; error
    @(114.9125 mm, 198.0000 mm): Pad 2 [GND] of R5 on F.Cu
    @(72.0000 mm, 200.5400 mm): PTH pad 2 [GND] of D2
[unconnected_items]: Missing connection between items
    Local override; error
    @(156.0000 mm, 74.5400 mm): PTH pad 2 [GND] of U4
    @(156.9125 mm, 114.0000 mm): Pad 2 [GND] of R1 on F.Cu
[unconnected_items]: Missing connection between items
    Local override; error
    @(156.0000 mm, 74.5400 mm): PTH pad 2 [GND] of U4
    @(114.0000 mm, 74.5400 mm): PTH pad 2 [GND] of U11
[unconnected_items]: Missing connection between items
    Local override; error
    @(156.0000 mm, 74.5400 mm): PTH pad 2 [GND] of U4
    @(156.0000 mm, 32.5400 mm): PTH pad 2 [GND] of U3
[unconnected_items]: Missing connection between items
    Local override; error
    @(156.9125 mm, 114.0000 mm): Pad 2 [GND] of R1 on F.Cu
    @(198.0000 mm, 116.5400 mm): PTH pad 2 [GND] of U9
[unconnected_items]: Missing connection between items
    Local override; error
    @(194.8500 mm, 27.7000 mm): Pad 1 [GND] of U12 on F.Cu
    @(156.0000 mm, 32.5400 mm): PTH pad 2 [GND] of U3
[unconnected_items]: Missing connection between items
    Local override; error
    @(198.0000 mm, 74.5400 mm): PTH pad 2 [GND] of U5
    @(240.0000 mm, 74.5400 mm): PTH pad 2 [GND] of U6
[unconnected_items]: Missing connection between items
    Local override; error
    @(198.0000 mm, 116.5400 mm): PTH pad 2 [GND] of U9
    @(198.0000 mm, 156.0000 mm): PTH pad 1 [GND] of Q1
[unconnected_items]: Missing connection between items
    Local override; error
    @(198.0000 mm, 116.5400 mm): PTH pad 2 [GND] of U9
    @(198.0000 mm, 74.5400 mm): PTH pad 2 [GND] of U5
[unconnected_items]: Missing connection between items
    Local override; error
    @(198.0000 mm, 156.0000 mm): PTH pad 1 [GND] of Q1
    @(198.0000 mm, 200.5400 mm): PTH pad 2 [GND] of PR1
[unconnected_items]: Missing connection between items
    Local override; error
    @(198.0000 mm, 200.5400 mm): PTH pad 2 [GND] of PR1
    @(156.0000 mm, 200.5400 mm): PTH pad 2 [GND] of U10
[unconnected_items]: Missing connection between items
    Local override; error
    @(198.0000 mm, 200.5400 mm): PTH pad 2 [GND] of PR1
    @(240.0000 mm, 200.5400 mm): PTH pad 2 [GND] of LCD1
[unconnected_items]: Missing connection between items
    Local override; error
    @(240.0000 mm, 82.1600 mm): PTH pad 5 [GND] of U6
    @(240.0000 mm, 74.5400 mm): PTH pad 2 [GND] of U6
[unconnected_items]: Missing connection between items
    Local override; error
    @(240.0000 mm, 121.6200 mm): PTH pad 4 [GND] of M1
    @(240.0000 mm, 82.1600 mm): PTH pad 5 [GND] of U6
[unconnected_items]: Missing connection between items
    Local override; error
    @(245.0000 mm, 30.0000 mm): PTH pad 2 [GND] of C1
    @(240.0000 mm, 74.5400 mm): PTH pad 2 [GND] of U6
[unconnected_items]: Missing connection between items
    Local override; error
    @(30.0000 mm, 50.3200 mm): PTH pad 17 [PRN_TX] of U1
    @(198.0000 mm, 203.0800 mm): PTH pad 3 [PRN_TX] of PR1
[unconnected_items]: Missing connection between items
    Local override; error
    @(32.5400 mm, 50.3200 mm): PTH pad 18 [PRN_RX] of U1
    @(198.0000 mm, 205.6200 mm): PTH pad 4 [PRN_RX] of PR1
[unconnected_items]: Missing connection between items
    Local override; error
    @(156.9125 mm, 156.0000 mm): Pad 2 [LED_DRAIN] of R2 on F.Cu
    @(200.5400 mm, 156.0000 mm): PTH pad 3 [LED_DRAIN] of Q1
[unconnected_items]: Missing connection between items
    Local override; error
    @(30.0000 mm, 119.0800 mm): PTH pad 3 [I2C_SDA] of U7
    @(72.0000 mm, 119.0800 mm): PTH pad 3 [I2C_SDA] of U8
[unconnected_items]: Missing connection between items
    Local override; error
    @(32.5400 mm, 32.5400 mm): PTH pad 4 [I2C_SDA] of U1
    @(30.0000 mm, 119.0800 mm): PTH pad 3 [I2C_SDA] of U7
[unconnected_items]: Missing connection between items
    Local override; error
    @(72.0000 mm, 119.0800 mm): PTH pad 3 [I2C_SDA] of U8
    @(114.0000 mm, 77.0800 mm): PTH pad 3 [I2C_SDA] of U11
[unconnected_items]: Missing connection between items
    Local override; error
    @(240.0000 mm, 77.0800 mm): PTH pad 3 [I2C_SDA] of U6
    @(114.0000 mm, 77.0800 mm): PTH pad 3 [I2C_SDA] of U11
[unconnected_items]: Missing connection between items
    Local override; error
    @(30.0000 mm, 35.0800 mm): PTH pad 5 [I2C_SCL] of U1
    @(30.0000 mm, 121.6200 mm): PTH pad 4 [I2C_SCL] of U7
[unconnected_items]: Missing connection between items
    Local override; error
    @(30.0000 mm, 121.6200 mm): PTH pad 4 [I2C_SCL] of U7
    @(72.0000 mm, 121.6200 mm): PTH pad 4 [I2C_SCL] of U8
[unconnected_items]: Missing connection between items
    Local override; error
    @(72.0000 mm, 121.6200 mm): PTH pad 4 [I2C_SCL] of U8
    @(114.0000 mm, 79.6200 mm): PTH pad 4 [I2C_SCL] of U11
[unconnected_items]: Missing connection between items
    Local override; error
    @(240.0000 mm, 79.6200 mm): PTH pad 4 [I2C_SCL] of U6
    @(114.0000 mm, 79.6200 mm): PTH pad 4 [I2C_SCL] of U11
[unconnected_items]: Missing connection between items
    Local override; error
    @(32.5400 mm, 35.0800 mm): PTH pad 6 [MOT_IN1] of U1
    @(198.0000 mm, 119.0800 mm): PTH pad 3 [MOT_IN1] of U9
[unconnected_items]: Missing connection between items
    Local override; error
    @(30.0000 mm, 37.6200 mm): PTH pad 7 [MOT_IN2] of U1
    @(198.0000 mm, 121.6200 mm): PTH pad 4 [MOT_IN2] of U9
[unconnected_items]: Missing connection between items
    Local override; error
    @(32.5400 mm, 37.6200 mm): PTH pad 8 [ENC_A] of U1
    @(240.0000 mm, 124.1600 mm): PTH pad 5 [ENC_A] of M1
[unconnected_items]: Missing connection between items
    Local override; error
    @(30.0000 mm, 40.1600 mm): PTH pad 9 [ENC_B] of U1
    @(240.0000 mm, 126.7000 mm): PTH pad 6 [ENC_B] of M1
[unconnected_items]: Missing connection between items
    Local override; error
    @(30.0000 mm, 158.5400 mm): PTH pad 2 [LIM_HOME] of SW1
    @(32.5400 mm, 40.1600 mm): PTH pad 10 [LIM_HOME] of U1
[unconnected_items]: Missing connection between items
    Local override; error
    @(30.0000 mm, 42.7000 mm): PTH pad 11 [LIM_END] of U1
    @(72.0000 mm, 158.5400 mm): PTH pad 2 [LIM_END] of SW2
[unconnected_items]: Missing connection between items
    Local override; error
    @(30.0000 mm, 45.2400 mm): PTH pad 13 [UVC_EN] of U1
    @(72.0000 mm, 203.0800 mm): PTH pad 3 [UVC_EN] of D2
[unconnected_items]: Missing connection between items
    Local override; error
    @(72.0000 mm, 203.0800 mm): PTH pad 3 [UVC_EN] of D2
    @(113.0875 mm, 198.0000 mm): Pad 1 [UVC_EN] of R5 on F.Cu
[unconnected_items]: Missing connection between items
    Local override; error
    @(32.5400 mm, 45.2400 mm): PTH pad 14 [HX_DT] of U1
    @(156.0000 mm, 203.0800 mm): PTH pad 3 [HX_DT] of U10
[unconnected_items]: Missing connection between items
    Local override; error
    @(30.0000 mm, 47.7800 mm): PTH pad 15 [HX_SCK] of U1
    @(156.0000 mm, 205.6200 mm): PTH pad 4 [HX_SCK] of U10
[unconnected_items]: Missing connection between items
    Local override; error
    @(30.0000 mm, 240.0000 mm): PTH pad 1 [SCAN_BTN] of SW3
    @(32.5400 mm, 47.7800 mm): PTH pad 16 [SCAN_BTN] of U1
[unconnected_items]: Missing connection between items
    Local override; error
    @(30.0000 mm, 52.8600 mm): PTH pad 19 [TFT_RST] of U1
    @(240.0000 mm, 205.6200 mm): PTH pad 4 [TFT_RST] of LCD1
[unconnected_items]: Missing connection between items
    Local override; error
    @(240.0000 mm, 213.2400 mm): PTH pad 7 [TFT_SCLK] of LCD1
    @(32.5400 mm, 52.8600 mm): PTH pad 20 [TFT_SCLK] of U1
[unconnected_items]: Missing connection between items
    Local override; error
    @(240.0000 mm, 220.8600 mm): PTH pad 10 [TFT_SCLK] of LCD1
    @(240.0000 mm, 213.2400 mm): PTH pad 7 [TFT_SCLK] of LCD1
[unconnected_items]: Missing connection between items
    Local override; error
    @(240.0000 mm, 210.7000 mm): PTH pad 6 [TFT_MOSI] of LCD1
    @(30.0000 mm, 55.4000 mm): PTH pad 21 [TFT_MOSI] of U1
[unconnected_items]: Missing connection between items
    Local override; error
    @(240.0000 mm, 225.9400 mm): PTH pad 12 [TFT_MOSI] of LCD1
    @(240.0000 mm, 210.7000 mm): PTH pad 6 [TFT_MOSI] of LCD1
[unconnected_items]: Missing connection between items
    Local override; error
    @(240.0000 mm, 218.3200 mm): PTH pad 9 [TFT_MISO] of LCD1
    @(32.5400 mm, 55.4000 mm): PTH pad 22 [TFT_MISO] of U1
[unconnected_items]: Missing connection between items
    Local override; error
    @(240.0000 mm, 228.4800 mm): PTH pad 13 [TFT_MISO] of LCD1
    @(240.0000 mm, 218.3200 mm): PTH pad 9 [TFT_MISO] of LCD1
[unconnected_items]: Missing connection between items
    Local override; error
    @(30.0000 mm, 57.9400 mm): PTH pad 23 [TFT_CS] of U1
    @(240.0000 mm, 203.0800 mm): PTH pad 3 [TFT_CS] of LCD1
[unconnected_items]: Missing connection between items
    Local override; error
    @(32.5400 mm, 57.9400 mm): PTH pad 24 [TFT_DC] of U1
    @(240.0000 mm, 208.1600 mm): PTH pad 5 [TFT_DC] of LCD1
[unconnected_items]: Missing connection between items
    Local override; error
    @(30.0000 mm, 60.4800 mm): PTH pad 25 [TFT_BL] of U1
    @(240.0000 mm, 215.7800 mm): PTH pad 8 [TFT_BL] of LCD1
[unconnected_items]: Missing connection between items
    Local override; error
    @(32.5400 mm, 60.4800 mm): PTH pad 26 [TOUCH_CS] of U1
    @(240.0000 mm, 223.4000 mm): PTH pad 11 [TOUCH_CS] of LCD1
[unconnected_items]: Missing connection between items
    Local override; error
    @(198.0000 mm, 124.1600 mm): PTH pad 5 [MOTOR_A] of U9
    @(240.0000 mm, 114.0000 mm): PTH pad 1 [MOTOR_A] of M1
[unconnected_items]: Missing connection between items
    Local override; error
    @(198.0000 mm, 126.7000 mm): PTH pad 6 [MOTOR_B] of U9
    @(240.0000 mm, 116.5400 mm): PTH pad 2 [MOTOR_B] of M1
[unconnected_items]: Missing connection between items
    Local override; error
    @(30.0000 mm, 114.0000 mm): PTH pad 1 [+3V3] of U7
    @(72.0000 mm, 114.0000 mm): PTH pad 1 [+3V3] of U8
[unconnected_items]: Missing connection between items
    Local override; error
    @(72.0000 mm, 114.0000 mm): PTH pad 1 [+3V3] of U8
    @(71.0500 mm, 72.0000 mm): Pad 1 [+3V3] of C3 on F.Cu
[unconnected_items]: Missing connection between items
    Local override; error
    @(114.0000 mm, 72.0000 mm): PTH pad 1 [+3V3] of U11
    @(114.0000 mm, 82.1600 mm): PTH pad 5 [+3V3] of U11
[unconnected_items]: Missing connection between items
    Local override; error
    @(114.0000 mm, 72.0000 mm): PTH pad 1 [+3V3] of U11
    @(156.0000 mm, 72.0000 mm): PTH pad 1 [+3V3] of U4
[unconnected_items]: Missing connection between items
    Local override; error
    @(114.0000 mm, 114.0000 mm): PTH pad 1 [+3V3] of RT1
    @(114.0000 mm, 82.1600 mm): PTH pad 5 [+3V3] of U11
[unconnected_items]: Missing connection between items
    Local override; error
    @(114.0000 mm, 114.0000 mm): PTH pad 1 [+3V3] of RT1
    @(72.0000 mm, 114.0000 mm): PTH pad 1 [+3V3] of U8
[unconnected_items]: Missing connection between items
    Local override; error
    @(156.0000 mm, 198.0000 mm): PTH pad 1 [+3V3] of U10
    @(114.0000 mm, 114.0000 mm): PTH pad 1 [+3V3] of RT1
[unconnected_items]: Missing connection between items
    Local override; error
    @(198.0000 mm, 72.0000 mm): PTH pad 1 [+3V3] of U5
    @(156.0000 mm, 72.0000 mm): PTH pad 1 [+3V3] of U4
[unconnected_items]: Missing connection between items
    Local override; error
    @(198.0000 mm, 72.0000 mm): PTH pad 1 [+3V3] of U5
    @(240.0000 mm, 72.0000 mm): PTH pad 1 [+3V3] of U6
[unconnected_items]: Missing connection between items
    Local override; error
    @(201.1500 mm, 30.0000 mm): Pad 2 [+3V3] of U12 on F.Cu
    @(194.8500 mm, 30.0000 mm): Pad 2 [+3V3] of U12 on F.Cu
[unconnected_items]: Missing connection between items
    Local override; error
    @(201.1500 mm, 30.0000 mm): Pad 2 [+3V3] of U12 on F.Cu
    @(198.0000 mm, 72.0000 mm): PTH pad 1 [+3V3] of U5
[unconnected_items]: Missing connection between items
    Local override; error
    @(240.0000 mm, 119.0800 mm): PTH pad 3 [+3V3] of M1
    @(240.0000 mm, 72.0000 mm): PTH pad 1 [+3V3] of U6
[unconnected_items]: Missing connection between items
    Local override; error
    @(72.0000 mm, 30.0000 mm): PTH pad 1 [VBAT] of BT1
    @(114.0000 mm, 35.0800 mm): PTH pad 3 [VBAT] of U2
[unconnected_items]: Missing connection between items
    Local override; error
    @(114.0000 mm, 92.3200 mm): PTH pad 9 [TCS1_SDA] of U11
    @(156.0000 mm, 77.0800 mm): PTH pad 3 [TCS1_SDA] of U4
[unconnected_items]: Missing connection between items
    Local override; error
    @(114.0000 mm, 94.8600 mm): PTH pad 10 [TCS1_SCL] of U11
    @(156.0000 mm, 79.6200 mm): PTH pad 4 [TCS1_SCL] of U4
[unconnected_items]: Missing connection between items
    Local override; error
    @(114.0000 mm, 97.4000 mm): PTH pad 11 [TCS2_SDA] of U11
    @(198.0000 mm, 77.0800 mm): PTH pad 3 [TCS2_SDA] of U5
[unconnected_items]: Missing connection between items
    Local override; error
    @(114.0000 mm, 99.9400 mm): PTH pad 12 [TCS2_SCL] of U11
    @(198.0000 mm, 79.6200 mm): PTH pad 4 [TCS2_SCL] of U5
[unconnected_items]: Missing connection between items
    Local override; error
    @(114.0000 mm, 156.0000 mm): PTH pad 1 [LED_NODE] of D1
    @(155.0875 mm, 156.0000 mm): Pad 1 [LED_NODE] of R2 on F.Cu
[unconnected_items]: Missing connection between items
    Local override; error
    @(114.0000 mm, 40.1600 mm): PTH pad 5 [VSYS] of U2
    @(156.0000 mm, 30.0000 mm): PTH pad 1 [VSYS] of U3
[unconnected_items]: Missing connection between items
    Local override; error
    @(121.6200 mm, 114.0000 mm): PTH pad 2 [NTC_SENSE] of RT1
    @(72.0000 mm, 126.7000 mm): PTH pad 6 [NTC_SENSE] of U8
[unconnected_items]: Missing connection between items
    Local override; error
    @(155.0875 mm, 114.0000 mm): Pad 1 [NTC_SENSE] of R1 on F.Cu
    @(121.6200 mm, 114.0000 mm): PTH pad 2 [NTC_SENSE] of RT1

** Found 0 Footprint errors **

** Ignored checks **
    - Footprint has no courtyard defined
    - Track endpoint not centered on via
    - Tuning profile track geometries
    - Footprint doesn't match symbol's footprint filters
    - Footprint component type doesn't match footprint pads

** End of Report **

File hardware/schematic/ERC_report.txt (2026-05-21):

ERC report (2026-05-21T16:20:56, Encoding UTF8)
Report includes: Errors, Warnings, Exclusions

***** Sheet /
[lib_symbol_issues]: The current configuration does not include the symbol library 'ual'
    ; warning
    @(50.80 mm, 30.48 mm): Symbol U1 [U1]
[isolated_pin_label]: Label connected to only one pin
    ; warning
    @(50.80 mm, 116.84 mm): Global Label 'VBUS'
[lib_symbol_issues]: The current configuration does not include the symbol library 'ual'
    ; warning
    @(50.80 mm, 116.84 mm): Symbol U2 [U2]
[lib_symbol_issues]: The current configuration does not include the symbol library 'ual'
    ; warning
    @(50.80 mm, 139.70 mm): Symbol U3 [U3]
[lib_symbol_issues]: The current configuration does not include the symbol library 'ual'
    ; warning
    @(50.80 mm, 157.48 mm): Symbol U12 [U12]
[lib_symbol_issues]: The current configuration does not include the symbol library 'ual'
    ; warning
    @(50.80 mm, 210.82 mm): Symbol U11 [U11]
[lib_symbol_issues]: The current configuration does not include the symbol library 'ual'
    ; warning
    @(50.80 mm, 248.92 mm): Symbol U4 [U4]
[lib_symbol_issues]: The current configuration does not include the symbol library 'ual'
    ; warning
    @(50.80 mm, 266.70 mm): Symbol U5 [U5]
[lib_symbol_issues]: The current configuration does not include the symbol library 'ual'
    ; warning
    @(50.80 mm, 284.48 mm): Symbol U6 [U6]
[lib_symbol_issues]: The current configuration does not include the symbol library 'ual'
    ; warning
    @(50.80 mm, 304.80 mm): Symbol U7 [U7]
[lib_symbol_issues]: The current configuration does not include the symbol library 'ual'
    ; warning
    @(50.80 mm, 325.12 mm): Symbol U8 [U8]
[lib_symbol_issues]: The current configuration does not include the symbol library 'ual'
    ; warning
    @(50.80 mm, 373.38 mm): Symbol U9 [U9]
[lib_symbol_issues]: The current configuration does not include the symbol library 'ual'
    ; warning
    @(50.80 mm, 396.24 mm): Symbol M1 [M1]
[lib_symbol_issues]: The current configuration does not include the symbol library 'ual'
    ; warning
    @(50.80 mm, 469.90 mm): Symbol Q1 [Q1]
[lib_symbol_issues]: The current configuration does not include the symbol library 'ual'
    ; warning
    @(50.80 mm, 510.54 mm): Symbol D2 [D2]
[lib_symbol_issues]: The current configuration does not include the symbol library 'ual'
    ; warning
    @(50.80 mm, 538.48 mm): Symbol U10 [U10]
[lib_symbol_issues]: The current configuration does not include the symbol library 'ual'
    ; warning
    @(147.32 mm, 30.48 mm): Symbol PR1 [PR1]
[lib_symbol_issues]: The current configuration does not include the symbol library 'ual'
    ; warning
    @(147.32 mm, 48.26 mm): Symbol LCD1 [LCD1]

 ** ERC messages: 18  Errors 0  Warnings 18

 ** Ignored checks:
    - Global label only appears once in the schematic
    - Four connection points are joined together
    - SPICE model issue
    - Assigned footprint doesn't match footprint filters

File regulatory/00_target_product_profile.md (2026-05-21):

# Target Product Profile — Urine Analyzer Lite

> Stage 0 Foundation document. Owner: Levram Lifesciences. Status: DRAFT (2026-05-21).
> This TPP is the reference against which all design, validation, and regulatory work is judged.
> Changing any row here may invalidate downstream validation — treat as a controlled document.

## 1. Intended Use Statement (draft)

> The Urine Analyzer Lite is an automated reflectance photometer intended for the
> semi-quantitative *in vitro* measurement of the following analytes in human urine,
> using compatible urine reagent test strips: leukocytes, nitrite, urobilinogen, protein,
> pH, blood, specific gravity, ketones, bilirubin, and glucose. It is intended for use by
> trained healthcare personnel at the point of care (clinics, physician offices, small
> labs). Results are intended as an aid to diagnosis and must be interpreted by a
> qualified clinician in the context of other clinical findings. Not for home/self-testing
> in the current configuration. Not for screening of blood or other body fluids.

## 2. Profile

| Attribute | Target | Notes |
|---|---|---|
| Product type | Automated urine reagent-strip reader (reflectance photometer) | Instrument; strips are a separate consumable |
| Analytes | 10-pad panel (leuko, nitrite, urobilinogen, protein, pH, blood, SG, ketones, bilirubin, glucose) | Matches standard commercial strip layout |
| Result type | Semi-quantitative (grades / concentration bands per analyte) | Not a true quantitative analyzer |
| Measurement principle | Optical reflectance; dual TCS34725 RGB sensors + high-CRI LED; HSV classification | See `analysis.h` |
| Sample | Human urine, applied to strip by operator | Device does not aspirate/handle free liquid beyond the wetted strip |
| Intended user | Trained healthcare personnel (nurse / technician / physician) | Drives IEC 62366 use spec; NOT lay user (see open issue) |
| Use environment | Clinic / point-of-care, indoor, 15–35 °C, 20–80% RH | Matches firmware environmental envelope |
| Throughput | Single strip per cycle | "Lite" positioning |
| Output | On-screen result + 58 mm thermal printout | ESC/POS |
| Connectivity | Optional Wi-Fi/BT result upload (roadmap) | If added, triggers cybersecurity assessment (Stage 8) |
| Power | Internal LiPo, USB-C charge | Portable |
| Strip compatibility | **OPEN ISSUE** — current design reads a standard commercial strip; business intent is a Levram-proprietary strip | Must resolve; see §4 |
| Shelf life (instrument) | Target ≥ 3 years | Reliability/Stage 7 |
| Target cost | <$250/unit at 50-unit volume (prototype ~₹387/$) | Per BOM |
| Market | India first (CDSCO); export (CE/510(k)) later | |

## 3. Performance targets (to be confirmed against predicate)

These are placeholders to be locked after a predicate-device benchmark and refined in Stage 6.

| Metric | Target | How verified |
|---|---|---|
| Agreement vs. visual read (per analyte) | ≥ 90% within ±1 grade | CLSI method comparison |
| Agreement vs. predicate analyzer | ≥ 90% concordance | Method comparison study |
| Repeatability (same strip lot, same sample) | ≥ 95% identical grade | CLSI EP05 |
| Carryover between strips | None detectable | Bench protocol |
| Reportable range | Per strip manufacturer's bands | |

## 4. Open issues blocking TPP sign-off

1. **Strip strategy (CRITICAL).** README/firmware currently read *standard commercial* strips,
   but stated business intent is to *develop a proprietary Levram strip*. These are different
   products with different scope, IFU, and regulatory dossiers. Decide before Stage 1.
   - If reading commercial strips: must declare compatible strip brand(s)/lot and calibrate to them; you do not control their chemistry or supply.
   - If proprietary strips: adds a full reagent-development + ISO 23640 stability + separate IVD registration track.
2. **User population.** TPP assumes trained personnel (POC clinic). If home use is ever
   in scope, usability/risk and possibly device class change.
3. **Quantitative vs semi-quantitative claim.** Keep semi-quantitative unless you can
   support a quantitative claim with validation — over-claiming is a regulatory risk.

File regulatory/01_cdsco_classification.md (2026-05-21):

# CDSCO Classification & Regulatory Pathway — Urine Analyzer Lite

> Stage 0 Foundation document. Status: DRAFT (2026-05-21).
> **This class must be confirmed by a CDSCO regulatory consultant via pre-submission
> BEFORE any validation data is generated.** Wrong class = wrong tests = repeated studies.

## 1. Regulatory framework
- **Medical Devices Rules, 2017 (MDR 2017)**, as amended, administered by **CDSCO** (Central
  Drugs Standard Control Organisation). IVDs are notified medical devices.
- IVDs are risk-classified **A / B / C / D** (low → high), per the IVD classification rules
  in MDR 2017 Schedule and CDSCO's published IVD classification lists.
- Submissions are made through the **CDSCO MD Online (SUGAM) portal**.

## 2. Classification analysis

The product is an **instrument (reagent-strip reader)**, not the reagent itself.

| Factor | Assessment |
|---|---|
| Analytes | Routine urinalysis params (glucose, protein, pH, etc.) — established, low individual risk |
| Risk if wrong result | Moderate: aids diagnosis, not sole basis; confirmatory testing standard of care |
| Public health risk | Not for blood screening / infectious-disease confirmation / self-testing |
| Precedent | Urine chemistry analyzers / urinalysis reagent-strip readers generally listed **Class B** |

**Best-guess class: B (low–moderate risk)** for the reader instrument.

> Caveats that could move it:
> - The **reagent strips** (if Levram-proprietary) are a *separate* IVD with their own
>   classification — per-analyte, often **B**, but some analytes can pull to **C**.
>   Glucose/blood/protein urine strips are typically B in India.
> - A **home/self-test** claim typically raises class and adds lay-user usability burden.
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

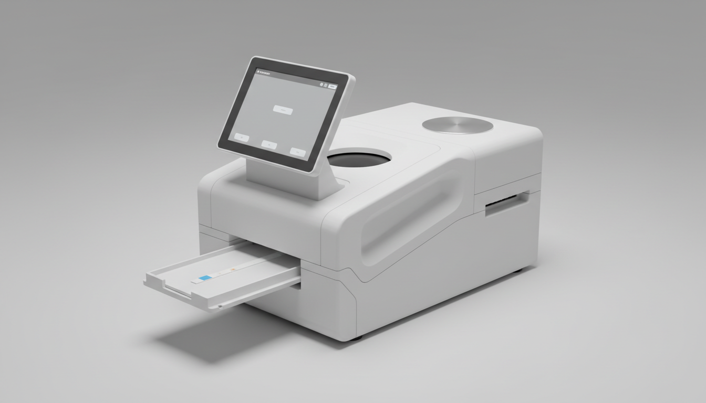
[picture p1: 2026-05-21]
design/blueprint/VISUAL.png

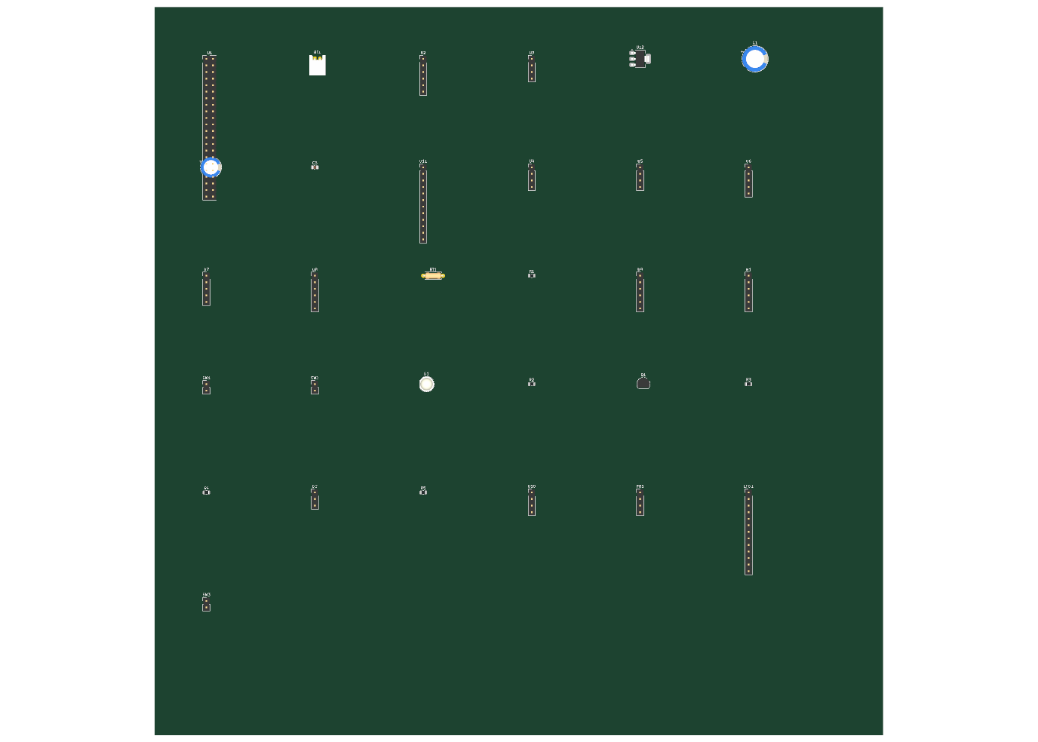
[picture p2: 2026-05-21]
hardware/pcb/urine_analyzer_lite_render_top.png

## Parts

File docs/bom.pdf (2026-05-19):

Bill of Materials — India Sourcing | Levram Lifesciences — Confidential
Urine Analyzer Lite | urine-analyzer-lite | Page 1

# Bill of Materials

## Urine Analyzer Lite | India Sourcing | Prices in INR (approx. ■84 = $1 USD)

Ref | Component | Description | Qty | Unit (■) | Total (■) | India Supplier | Sourcing Note
U1 | ESP32-S3-DevKitC-1 | Dual-core MCU with native USB; 8MB flash + 8MB OPI PSRAM | 1 | 1299 | 1299 | Robocraze | Also on Amazon.in ~■1350; Evelta stocks too
U2 | TP4056 USB-C Module | LiPo charging module with USB-C input and protection circuit | 1 | 65 | 65 | Robocraze | Very common; also at Probots / Amazon.in ~■60
U3 | S13V25F5 Buck-Boost Regulator | 5 V 2.5 A step-up/step-down regulator from LiPo | 1 | 1099 | 1099 | Mouser India | Pololu product; Mouser.in stocks it. element14.in alternate
BT1 | 3.7V 2000mAh LiPo | Main rechargeable power source | 1 | 599 | 599 | Robocraze | Probots also carries; verify protection circuit included
U4 | TCS34725 RGB Sensor #1 | I2C RGB+clear color sensor with IR cut filter (primary pad sensor) | 1 | 649 | 649 | Robocraze | Evelta ~■700; confirm IR-cut filter present on module
U5 | TCS34725 RGB Sensor #2 | I2C RGB+clear color sensor (secondary / differential) | 1 | 649 | 649 | Robocraze | Same part as U4; buy 2 together for small discount
U6 | SHT31-D Module | High-accuracy I2C temperature and humidity sensor | 1 | 749 | 749 | Probots | Robocraze alternate ~■780; avoid clone modules for accuracy
U7 | BH1750 FVI | I2C digital ambient light sensor | 1 | 149 | 149 | Robocraze | Amazon.in ~■160; very common; GY-302 breakout widely available
U8 | ADS1115 ADC Module | 16-bit I2C ADC with PGA for NTC thermistor | 1 | 449 | 449 | Robocraze | Probots ~■400; Evelta ~■480
RT1 | NTC Thermistor 10k B3950 | Temperature sensing inside optical chamber | 1 | 25 | 25 | Electronicscomp | Sunrom.com ~■20; sold in packs of 5 — buy pack
U9 | MX1508 Dual H-Bridge | Dual DC motor driver 2A per channel | 1 | 120 | 120 | Robocraze | Amazon.in ~■100; Robokits ~■110
M1 | GA12-N20 6V 200RPM + Encoder | Compact DC gear motor with Hall-effect quadrature encoder | 1 | 449 | 449 | Robocraze | Robokits ~■500; confirm 6V 200RPM variant with encoder
SW1 | KW12-3 Micro Limit Switch | Home position limit switch (NO) | 1 | 65 | 65 | Robocraze | Amazon.in ■50–80; buy pack of 5 for spares
SW2 | KW12-3 Micro Limit Switch | End-of-travel limit switch (NO) | 1 | 65 | 65 | Robocraze | Same as SW1; order 4 total (2 working + 2 spares)
D1 | High-CRI 5mm LED 95+ CRI | High colour-rendering white illumination LED for pad reading | 1 | 220 | 220 | Mouser India | IMPORT — no Indian-stocked 95+CRI 5mm LED equivalent; Nichia NSPWR70CSS-K1 via Mouser.in. Budget alternative: 90CRI Cree-equiv from Amazon.in ~■80
Q1 | 2N7000 N-Channel MOSFET | PWM control MOSFET for illumination LED | 1 | 15 | 15 | Electronicscomp | Sunrom.com ~■20; sold loose — buy 10 for <■100
D2 | 275nm UVC LED Module | UV-C sterilization LED for tray decontamination | 1 | 1050 | 1050 | Mouser India | IMPORT — Mouser.in stocks Klaran / SETi UVC LEDs; order with heatsink. element14.in alternate. Allow 2-week lead time
U10 | HX711 Load Cell Amplifier Kit 1kg | 24-bit ADC for load cell weight measurement | 1 | 320 | 320 | Robocraze | Includes 1 kg bar-type load cell; Probots ~■350

Bill of Materials — India Sourcing | Levram Lifesciences — Confidential
Ref | Component | Description | Qty | Unit (■) | Total (■) | India Supplier | Sourcing Note
PR1 | CSN-A2 Micro Thermal Printer | 58mm thermal receipt printer for diagnostic reports | 1 | 2800 | 2800 | Robocraze | Amazon.in ■2500–3200 depending on seller; verify TTL UART version (not USB-only)
LCD1 | Waveshare 4.3in DSI LCD | Capacitive touch display; MIPI DSI interface | 1 | 3999 | 3999 | Evelta | Robocraze ~■4200; verify DSI cable included. Waveshare India authorised reseller: robu.in
SW3 | Momentary Tactile Button 6x6mm | Scan trigger button | 1 | 5 | 5 | Electronicscomp | Sunrom ~■4; buy strip of 20 (<■80 total)
-- | GT2 Timing Belt 200mm 6mm wide | Belt drive for strip-tray linear motion | 1 | 199 | 199 | Robocraze | Amazon.in ~■180; buy 2 (one spare)
-- | GT2 Pulley 16T 3mm bore | Aluminium motor and idler pulleys | 2 | 175 | 350 | Robocraze | Amazon.in ~■150 each
-- | M3 Stainless Socket Head Screws M3×10 | General chassis fasteners | 20 | 4 | 80 | Amazon India | Buy 50-pack ~■150 for spares
-- | M3 Brass Heat-Set Inserts M3×5 | Threaded inserts for 3D-printed parts | 12 | 8 | 96 | Amazon India | Robocraze carries too; buy 20-pack
-- | Frosted Acrylic Sheet 50×20×2mm | LED diffuser plate in optical chamber | 1 | 180 | 180 | Amazon India | Cut from A4 sheet ~■300; local acrylic shop in most cities cheaper
-- | 2mm Clear Acrylic Sheet (laser cut) | Strip flattening guard over tray | 1 | 250 | 250 | Amazon India | Local laser cutting shop (Lamington Rd Mumbai / Nehru Place Delhi) cheaper than online
-- | Aluminium Sheet 80×40×2mm | UV-C safety shield (internal) | 1 | 320 | 320 | Amazon India | Local hardware/metal supplier; cut from 200×200mm sheet
-- | Spectralon 99% White Standard 10×10mm | White calibration standard for sensor normalisation | 1 | 2200 | 2200 | Labsphere (import) | IMPORT — no India distributor; ship via FedEx International. DIY alternative: pressed BaSO4 tablet (~■200 at lab chemicals supplier like HiMedia)
-- | Whatman Grade 1 Filter Paper Strips | Disposable tray liners pack of 100 | 100 | 12 | 1200 | Merck India | HiMedia Laboratories (Mumbai/Delhi/Chennai) alternate; also Amazon.in ~■1400 for pack
-- | Chassis Base (3D print – PLA) | Compact main chassis 160×120×55mm | 1 | 300 | 300 | Self / Local bureau | PLA ~■900/kg on Amazon.in (eSun / Bambu); 3D printing bureaus in major cities ~■5–8/gram
-- | Optical Chamber (3D print – Black PLA) | Light-tight sensor housing 65×30×45mm | 1 | 175 | 175 | Self / Local bureau | Must be Black PLA; 100% infill adds material cost
-- | Dipstick Tray (3D print – PLA) | Single 6mm strip channel with filter-paper slot | 1 | 175 | 175 | Self / Local bureau | Print in natural/white PLA; replace each batch run if contaminated
-- | MCU Tray (3D print – PLA) | Snap-fit bracket for ESP32-S3-DevKitC-1 | 1 | 45 | 45 | Self / Local bureau | Simple flat part; low print cost
-- | Printer Bracket (3D print – PETG) | Mount for CSN-A2 thermal printer | 1 | 220 | 220 | Self / Local bureau | PETG ~■1200/kg; use for heat-resistant parts near printer
-- | Display Bezel (3D print – PLA) | Front panel with 4.3in LCD cutout | 1 | 130 | 130 | Self / Local bureau | Sand and paint for professional finish
-- | UV-C Shield (3D print – Black PLA) | Internal shroud for UV-C LED | 1 | 90 | 90 | Self / Local bureau | 100% infill; UV-stable PLA preferred
-- | Belt Tensioner (3D print – PLA) | Adjustable GT2 idler arm | 1 | 90 | 90 | Self / Local bureau | Pair with 625ZZ bearing (■60 on Amazon.in)
-- | Limit Switch Bracket ×2 (3D print – PLA) | Adjustable KW12-3 mount | 2 | 25 | 50 | Self / Local bureau | Small part; minimal material

Bill of Materials — India Sourcing | Levram Lifesciences — Confidential
Ref | Component | Description | Qty | Unit (■) | Total (■) | India Supplier | Sourcing Note
-- | N20 Motor Bracket (3D print – PLA) | Adapter to mount N20 motor to chassis | 1 | 45 | 45 | Self / Local bureau | Print in PETG if near motor heat
| | | | TOTAL (INR) | | 26156
| | | | TOTAL (USD approx @ ■84) | | ~311

Note: Items marked IMPORT require ordering via Mouser India (mouser.in) or element14 India (in.element14.com). Allow 1–2 week lead time. 3D-printed parts use self-sourced PLA/PETG filament (~■900–1200/kg on Amazon.in).

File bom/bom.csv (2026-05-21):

Ref | Name | Description | Category | Type | Qty | Unit Cost (INR) | Total Cost (INR) | India Supplier | India URL | Sourcing Note
U1 | ESP32-S3-DevKitC-1 | Dual-core MCU with native USB; 8MB flash + 8MB OPI PSRAM | Electrical | MCU | 1 | 1299 | 1299 | Robocraze | https://robocraze.com/products/esp32-s3-devkitc-1-n8r8 | Also on Amazon.in ~₹1350; Evelta stocks too
U2 | TP4056 USB-C Module | LiPo charging module with USB-C input and protection circuit | Electrical | Power | 1 | 65 | 65 | Robocraze | https://robocraze.com/products/tp4056-type-c-usb-5v-1a-18650-lithium-battery-charger-module | Very common; also at Probots / Amazon.in ~₹60
U3 | S13V25F5 Buck-Boost Regulator | 5 V 2.5 A step-up/step-down regulator from LiPo | Electrical | Power | 1 | 1099 | 1099 | Mouser India | https://www.mouser.in/ProductDetail/Pololu/2775 | Pololu product; Mouser.in stocks it. element14.in alternate
BT1 | 3.7V 2000mAh LiPo | Main rechargeable power source | Electrical | Power | 1 | 599 | 599 | Robocraze | https://robocraze.com/products/3-7v-2000mah-lipo-battery | Probots also carries; verify protection circuit included
U4 | TCS34725 RGB Sensor #1 | I2C RGB+clear color sensor with IR cut filter (primary pad sensor) | Electrical | Sensor | 1 | 649 | 649 | Robocraze | https://robocraze.com/products/tcs34725-rgb-color-sensor-module | Evelta ~₹700; confirm IR-cut filter present on module
U5 | TCS34725 RGB Sensor #2 | I2C RGB+clear color sensor (secondary / differential) | Electrical | Sensor | 1 | 649 | 649 | Robocraze | https://robocraze.com/products/tcs34725-rgb-color-sensor-module | Same part as U4; buy 2 together for small discount
U6 | SHT31-D Module | High-accuracy I2C temperature and humidity sensor | Electrical | Sensor | 1 | 749 | 749 | Probots | https://probots.co.in/sht31-d-temperature-humidity-sensor-breakout.html | Robocraze alternate ~₹780; avoid clone modules for accuracy
U7 | BH1750 FVI | I2C digital ambient light sensor | Electrical | Sensor | 1 | 149 | 149 | Robocraze | https://robocraze.com/products/bh1750-light-intensity-sensor-module | Amazon.in ~₹160; very common; GY-302 breakout widely available
U8 | ADS1115 ADC Module | 16-bit I2C ADC with PGA for NTC thermistor | Electrical | Module | 1 | 449 | 449 | Robocraze | https://robocraze.com/products/ads1115-16-bit-adc-4-channel-with-pro-gain-amplifier | Probots ~₹400; Evelta ~₹480
RT1 | NTC Thermistor 10k B3950 | Temperature sensing inside optical chamber | Electrical | Sensor | 1 | 25 | 25 | Electronicscomp | https://www.electronicscomp.com/10k-ohm-ntc-thermistor-india | Sunrom.com ~₹20; sold in packs of 5 — buy pack
U9 | MX1508 Dual H-Bridge | Dual DC motor driver 2A per channel | Electrical | Module | 1 | 120 | 120 | Robocraze | https://robocraze.com/products/mx1508-dual-dc-motor-driver-module | Amazon.in ~₹100; Robokits ~₹110
M1 | GA12-N20 6V 200RPM + Encoder | Compact DC gear motor with Hall-effect quadrature encoder | Electrical | Actuator | 1 | 449 | 449 | Robocraze | https://robocraze.com/products/n20-dc-gear-motor-with-encoder-6v-200-rpm | Robokits ~₹500; confirm 6V 200RPM variant with encoder
SW1 | KW12-3 Micro Limit Switch | Home position limit switch (NO) | Electrical | Sensor | 1 | 65 | 65 | Robocraze | https://robocraze.com/products/micro-limit-switch | Amazon.in ₹50–80; buy pack of 5 for spares
SW2 | KW12-3 Micro Limit Switch | End-of-travel limit switch (NO) | Electrical | Sensor | 1 | 65 | 65 | Robocraze | https://robocraze.com/products/micro-limit-switch | Same as SW1; order 4 total (2 working + 2 spares)
D1 | High-CRI 5mm LED 95+ CRI | High colour-rendering white illumination LED for pad reading | Electrical | Actuator | 1 | 220 | 220 | Mouser India | https://www.mouser.in/c/?q=95+CRI+5mm+LED | IMPORT — no Indian-stocked 95+CRI 5mm LED equivalent; Nichia NSPWR70CSS-K1 via Mouser.in. Budget alternative: 90CRI Cree-equiv from Amazon.in ~₹80
Q1 | 2N7000 N-Channel MOSFET | PWM control MOSFET for illumination LED | Electrical | Module | 1 | 15 | 15 | Electronicscomp | https://www.electronicscomp.com/2n7000-n-channel-mosfet-transistor-india | Sunrom.com ~₹20; sold loose — buy 10 for <₹100
D2 | 275nm UVC LED Module | UV-C sterilization LED for tray decontamination | Electrical | Actuator | 1 | 1050 | 1050 | Mouser India | https://www.mouser.in/c/?q=UVC+LED+275nm | IMPORT — Mouser.in stocks Klaran / SETi UVC LEDs; order with heatsink. element14.in alternate. Allow 2-week lead time
U10 | HX711 Load Cell Amplifier Kit 1kg | 24-bit ADC for load cell weight measurement | Electrical | Module | 1 | 320 | 320 | Robocraze | https://robocraze.com/products/hx711-weight-sensor-load-cell-amplifier-module | Includes 1 kg bar-type load cell; Probots ~₹350
PR1 | CSN-A2 Micro Thermal Printer | 58mm thermal receipt printer for diagnostic reports | Electrical | Actuator | 1 | 2800 | 2800 | Robocraze | https://robocraze.com/products/mini-thermal-receipt-printer-module-ttl-serial | Amazon.in ₹2500–3200 depending on seller; verify TTL UART version (not USB-only)
LCD1 | 3.5in SPI TFT (ILI9488) with XPT2046 touch | SPI display 480x320 with resistive touch; ESP32-S3 native SPI | Electrical | Display | 1 | 950 | 950 | Robocraze | https://robocraze.com/products/3-5-inch-tft-lcd-touch-screen | REPLACES Waveshare 4.3in DSI LCD — ESP32-S3 has no MIPI-DSI. ST7796 4.0in is a drop-in alt. Amazon.in ₹850–1200
U11 | TCA9548A I2C Multiplexer | 8-channel I2C mux to separate the two TCS34725 (both fixed at 0x29) | Electrical | Module | 1 | 299 | 299 | Robocraze | https://robocraze.com/products/tca9548a-i2c-multiplexer | REQUIRED — two TCS34725 cannot share 0x29 on one bus. Evelta/Probots alternates ~₹320
U12 | AMS1117-3.3 Regulator | 3.3V LDO from 5V rail for the sensor bus (no dedicated 3V3 rail otherwise) | Electrical | Power | 1 | 35 | 35 | Electronicscomp | https://www.electronicscomp.com/ams1117-3.3v-voltage-regulator | Sold on small breakout ~₹40; or use ESP32-S3 DevKit 3V3 pin if sensor current stays low (verify budget)
SW3 | Momentary Tactile Button 6x6mm | Scan trigger button | Electrical | Sensor | 1 | 5 | 5 | Electronicscomp | https://www.electronicscomp.com/6x6mm-push-button-tactile-switch-4pin-india | Sunrom ~₹4; buy strip of 20 (<₹80 total)
-- | GT2 Timing Belt 200mm 6mm wide | Belt drive for strip-tray linear motion | Mechanical | Mechanism | 1 | 199 | 199 | Robocraze | https://robocraze.com/products/gt2-timing-belt-6mm-width-200mm-closed | Amazon.in ~₹180; buy 2 (one spare)
-- | GT2 Pulley 16T 3mm bore | Aluminium motor and idler pulleys | Mechanical | Mechanism | 2 | 175 | 350 | Robocraze | https://robocraze.com/products/gt2-timing-pulley-16-teeth-3mm-bore | Amazon.in ~₹150 each
-- | M3 Stainless Socket Head Screws M3×10 | General chassis fasteners | Mechanical | Hardware | 20 | 4 | 80 | Amazon India | https://www.amazon.in/s?k=M3+stainless+socket+head+screw+10mm | Buy 50-pack ~₹150 for spares
-- | M3 Brass Heat-Set Inserts M3×5 | Threaded inserts for 3D-printed parts | Mechanical | Hardware | 12 | 8 | 96 | Amazon India | https://www.amazon.in/s?k=M3+brass+heat+set+insert | Robocraze carries too; buy 20-pack
-- | Frosted Acrylic Sheet 50×20×2mm | LED diffuser plate in optical chamber | Mechanical | Structural | 1 | 180 | 180 | Amazon India | https://www.amazon.in/s?k=frosted+acrylic+sheet+2mm | Cut from A4 sheet ~₹300; local acrylic shop in most cities cheaper
-- | 2mm Clear Acrylic Sheet (laser cut) | Strip flattening guard over tray | Mechanical | Structural | 1 | 250 | 250 | Amazon India | https://www.amazon.in/s?k=clear+acrylic+sheet+2mm | Local laser cutting shop (Lamington Rd Mumbai / Nehru Place Delhi) cheaper than online
-- | Aluminium Sheet 80×40×2mm | UV-C safety shield (internal) | Mechanical | Structural | 1 | 320 | 320 | Amazon India | https://www.amazon.in/s?k=aluminium+sheet+2mm | Local hardware/metal supplier; cut from 200×200mm sheet
-- | Spectralon 99% White Standard 10×10mm | White calibration standard for sensor normalisation | Mechanical | Calibration | 1 | 2200 | 2200 | Labsphere (import) | https://www.labsphere.com/product/spectralon-diffuse-reflectance-standards/ | IMPORT — no India distributor; ship via FedEx International. DIY alternative: pressed BaSO4 tablet (~₹200 at lab chemicals supplier like HiMedia)
-- | Whatman Grade 1 Filter Paper Strips | Disposable tray liners pack of 100 | Mechanical | Consumable | 100 | 12 | 1200 | Merck India | https://www.merckmillipore.com/IN/en/product/Whatman-Grade-1-Qualitative-Filter-Paper/MM_NF-WHA1001090 | HiMedia Laboratories (Mumbai/Delhi/Chennai) alternate; also Amazon.in ~₹1400 for pack
-- | Chassis Base (3D print – PLA) | Compact main chassis 160×120×55mm | Mechanical | 3D Printed | 1 | 300 | 300 | Self / Local bureau | N/A | PLA ~₹900/kg on Amazon.in (eSun / Bambu); 3D printing bureaus in major cities ~₹5–8/gram
-- | Optical Chamber (3D print – Black PLA) | Light-tight sensor housing 65×30×45mm | Mechanical | 3D Printed | 1 | 175 | 175 | Self / Local bureau | N/A | Must be Black PLA; 100% infill adds material cost
-- | Dipstick Tray (3D print – PLA) | Single 6mm strip channel with filter-paper slot | Mechanical | 3D Printed | 1 | 175 | 175 | Self / Local bureau | N/A | Print in natural/white PLA; replace each batch run if contaminated
-- | MCU Tray (3D print – PLA) | Snap-fit bracket for ESP32-S3-DevKitC-1 | Mechanical | 3D Printed | 1 | 45 | 45 | Self / Local bureau | N/A | Simple flat part; low print cost
-- | Printer Bracket (3D print – PETG) | Mount for CSN-A2 thermal printer | Mechanical | 3D Printed | 1 | 220 | 220 | Self / Local bureau | N/A | PETG ~₹1200/kg; use for heat-resistant parts near printer
-- | Display Bezel (3D print – PLA) | Front panel with 4.3in LCD cutout | Mechanical | 3D Printed | 1 | 130 | 130 | Self / Local bureau | N/A | Sand and paint for professional finish
-- | UV-C Shield (3D print – Black PLA) | Internal shroud for UV-C LED | Mechanical | 3D Printed | 1 | 90 | 90 | Self / Local bureau | N/A | 100% infill; UV-stable PLA preferred
-- | Belt Tensioner (3D print – PLA) | Adjustable GT2 idler arm | Mechanical | 3D Printed | 1 | 90 | 90 | Self / Local bureau | N/A | Pair with 625ZZ bearing (₹60 on Amazon.in)
-- | Limit Switch Bracket ×2 (3D print – PLA) | Adjustable KW12-3 mount | Mechanical | 3D Printed | 2 | 25 | 50 | Self / Local bureau | N/A | Small part; minimal material
-- | N20 Motor Bracket (3D print – PLA) | Adapter to mount N20 motor to chassis | Mechanical | 3D Printed | 1 | 45 | 45 | Self / Local bureau | N/A | Print in PETG if near motor heat
 |  |  |  |  |  | TOTAL (INR) |  | 26156
 |  |  |  |  |  | TOTAL (USD approx @ ₹84) |  | ~311

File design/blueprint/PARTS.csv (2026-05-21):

Name | Product Name | Description | Category | Type | Quantity | Estimated Cost | Total Cost | URL
Home Limit Switch | KW12-3 Micro Limit Switch | Mechanical switch for manual touch-off height sensing. | electrical | sensor | 1 | 1.50 | 1.50 | https://www.digikey.com/en/products/result?keywords=micro+limit+switch
End Limit Switch | KW12-3 Micro Limit Switch | Mechanical switch for manual touch-off height sensing. | electrical | sensor | 1 | 1.50 | 1.50 | https://www.digikey.com/en/products/result?keywords=micro+limit+switch
Environmental Sensor | SHT31-D Module | High-accuracy digital temperature and humidity sensor with I2C interface for high sensitivity. | electrical | sensor | 1 | 8.50 | 8.50 | https://www.adafruit.com/product/2857
Ambient Light Sensor | BH1750 FVI |  | electrical | sensor | 1 | 4.00 | 4.00 | https://www.amazon.com/s?k=BH1750+sensor
Illumination LED | 5mm Warm White LED 3000K |  | electrical | actuator | 1 | 0.20 | 0.20 | https://www.digikey.com/en/products/result?keywords=5mm+white+led
UV-C Sterilization LED | 275nm UVC LED Module |  | electrical | actuator | 1 | 12.00 | 12.00 | https://www.digikey.com/en/products/result?keywords=UVC+LED+275nm
System Battery | 3.7V 2000mAh LiPo | Main power source for the device. | electrical | power | 1 | 14.00 | 14.00 | https://www.adafruit.com/product/2011
USB-C Charger | TP4056 USB-C Module | Manages charging of the LiPo battery via a USB-C input. | electrical | power | 1 | 2.50 | 2.50 | https://www.amazon.com/s?k=TP4056+USB-C
5V/9V Voltage Regulator | S13V25F5 Multi-Regulator |  | electrical | power | 1 | 12.00 | 12.00 | https://www.pololu.com/category/133/step-up-step-down-voltage-regulators
Optical Chamber Housing | Optical Chamber Housing | Light-tight enclosure for the photodiode and LED array to ensure consistent readings. | mechanical | 3d_printed | 1 | 2.00 | 2.00 | https://www.amazon.com/s?k=Black+PLA+filament
MCU Mounting Tray | MCU Mounting Tray | Snap-fit bracket for the ESP32-S3 controller board. | mechanical | 3d_printed | 1 | 0.50 | 0.50 | https://www.amazon.com/s?k=PLA+filament
Home Switch Bracket | Home Switch Bracket | Adjustable mount for the home position limit switch. | mechanical | 3d_printed | 1 | 0.30 | 0.30 | https://www.amazon.com/s?k=limit+switch+mount
End Switch Bracket | End Switch Bracket | Adjustable mount for the end-of-travel limit switch. | mechanical | 3d_printed | 1 | 0.30 | 0.30 | https://www.amazon.com/s?k=limit+switch+mount
M3 Hardware Pack | M3 Stainless Socket Head Screws | Various M3 screws for mounting motors, rails, and PCB supports. | mechanical | misc | 20 | 0.05 | 1.00 | https://www.amazon.com/s?k=M3+screw+assortment
M3 Heat-Set Inserts | M3 Brass Threaded Inserts | Brass inserts for creating durable threads in 3D-printed parts. | mechanical | misc | 12 | 0.15 | 1.80 | https://www.amazon.com/s?k=M3+heat+set+inserts
LED Diffuser Plate | Frosted Acrylic Sheet | Diffuses the white LED array for uniform illumination of reagent pads. | mechanical | structural | 1 | 2.50 | 2.50 | https://www.amazon.com/s?k=frosted+acrylic+sheet
UV-C Safety Shield |  | Protective internal shield to prevent UV-C leakage during sterilization. | mechanical | enclosure | 1 | 4.00 | 4.00 | https://www.homedepot.com/s/aluminum+sheet
Environmental Sensor Mount | Environmental Sensor Mount | Form-fitting cradle for the Environmental Sensor that holds the sensing surface in its rated orientation. Snap-fit retention so it can be removed for calibration without tools. | mechanical | 3d_printed | 1 | 2.00 | 2.00
Ambient Light Sensor Mount | Ambient Light Sensor Mount | Form-fitting cradle for the Ambient Light Sensor that holds the sensing surface in its rated orientation. Snap-fit retention so it can be removed for calibration without tools. | mechanical | 3d_printed | 1 | 2.00 | 2.00
Illumination LED Mount | Illumination LED Mount | Per-position bracket for the Illumination LED with M3 mounting holes matched to its bolt pattern. Rated for the actuator's continuous torque/load class. | mechanical | 3d_printed | 1 | 2.00 | 2.00
UV-C Sterilization LED Mount |  | Per-position bracket for the UV-C Sterilization LED with M3 mounting holes matched to its bolt pattern. Rated for the actuator's continuous torque/load class. | mechanical | 3d_printed | 1 | 2.00 | 2.00
Calibration Target | Labsphere Spectralon White Standard 99% 10x10mm | Highly Lambertian white reflectance standard for normalizing spectral sensor data. | mechanical | misc | 1 | 25.00 | 25.00 | https://www.labsphere.com/product/spectralon-diffuse-reflectance-standards/
RGB Color Sensor | Adafruit TCS34725 RGB Color Sensor | High-accuracy RGB color sensor with IR filter and I2C interface for consistent color measurement. | electrical | sensor | 1 | 7.95 | 7.95 | https://www.adafruit.com/product/1334
RGB Sensor Mount | TCS34725 Custom Bracket | 3D-printed bracket to secure the TCS34725 sensor inside the optical chamber. | mechanical | 3d_printed | 1 | 0.50 | 0.50 | https://www.printables.com/search/models?q=TCS34725+mount
Secondary RGB Sensor | Adafruit TCS34725 RGB Color Sensor | Second color sensor for differential or redundant reagent pad analysis. | electrical | sensor | 1 | 7.95 | 7.95 | https://www.adafruit.com/product/1334
GT2 Timing Belt | GT2 Timing Belt 2mm Pitch 6mm Wide | Rubber belt used to translate rotational motion of the DC motor into linear motion. | mechanical | mechanism | 1 | 5.00 | 5.00 | https://www.amazon.com/s?k=GT2+timing+belt+200mm
GT2 Pulley | GT2 Timing Pulley 16 Teeth 3mm Bore | Aluminum pulleys for the belt drive system. | mechanical | mechanism | 2 | 3.00 | 6.00 | https://www.amazon.com/s?k=GT2+pulley+3mm+bore
Belt Tensioner | 3D Printed Belt Tensioner | Adjustable mount to maintain proper tension on the timing belt. | mechanical | 3d_printed | 1 | 1.00 | 1.00 | N/A
16-Bit ADC Module | ADS1115 4-Channel ADC with PGA | High-precision 16-bit analog-to-digital converter to handle low-noise sensor data. | electrical | module | 1 | 6.50 | 6.50 | https://www.adafruit.com/product/1085
High-CRI Reference LED | YujiLEDs 95+ CRI 5mm LED | Broad-spectrum white LED with high color rendering index for medical diagnostic accuracy. | electrical | actuator | 1 | 2.50 | 2.50 | https://www.yujiintl.com/high-cri-led-bulbs/
Light Shield Shroud | Custom 3D-Printed Light Shield | An opaque gasket or shroud to seal the optical chamber against the dipstick surface. | mechanical | 3d_printed | 1 | 1.50 | 1.50 | N/A
Scan Start Button | Momentary Tactile Push Button 6x6mm | Triggers the automated measurement sequence when pressed. | electrical | sensor | 1 | 0.10 | 0.10 | https://www.digikey.com/en/products/result?keywords=momentary+tactile+button
LED Control MOSFET | 2N7000 N-Channel MOSFET | Allows MCU to control High-CRI LED intensity via PWM for calibration. | electrical | module | 1 | 0.50 | 0.50 | https://www.digikey.com/en/products/result?keywords=2N7000
Main Controller S3 | ESP32-S3-DevKitC-1 | Powerful dual-core MCU with native USB and enough RAM for UI rendering. | electrical | mcu | 1 | 15.00 | 15.00 | https://www.digikey.com/en/products/detail/espressif-systems/ESP32-S3-DEVKITC-1-N8R8/16162639
Manufacturable Main Shell | Custom ABS Enclosure | Enclosure designed with 2-degree draft angles and uniform wall thickness for high-volume production. | mechanical | enclosure | 1 | 15.00 | 15.00 | N/A
Disposable Tray Liner | Whatman Grade 1 Filter Paper Strips | Pre-cut absorbent strips to be placed in the tray reservoir to soak up excess urine. | mechanical | misc | 100 | 0.15 | 15.00 | https://www.amazon.com/s?k=filter+paper+strips
Clear Acrylic Guard | 2mm Clear Acrylic Sheet (Laser Cut) | A low-friction clear plate that holds the dipstick flat against the tray as the optical head passes over. | mechanical | structural | 1 | 3.00 | 3.00 | https://www.amazon.com/s?k=clear+acrylic+sheet+2mm
Single-Strip Mini Tray | Miniature Dipstick Tray | Compact tray designed with a single 6mm wide channel for a single reagent strip. | mechanical | 3d_printed | 1 | 2.00 | 2.00 | https://www.amazon.com/s?k=PLA+filament
Compact Chassis Base | Compact Main Chassis | Redesigned chassis base with a smaller overall footprint and optimized mounting for the single-strip tray. | mechanical | 3d_printed | 1 | 3.50 | 3.50 | https://www.amazon.com/s?k=PLA+filament
Thermal Receipt Printer | CSN-A2 Micro Thermal Printer | Integrated thermal printer for diagnostic reports. | electrical | actuator | 1 | 35.00 | 35.00 | https://www.adafruit.com/product/597
Weight Sensor | HX711 Load Cell Kit 1kg | Senses sample cup placement and volume verification. | electrical | sensor | 1 | 8.00 | 8.00 | https://www.amazon.com/s?k=HX711+load+cell+kit
4.3in Capacitive Touch Display | Waveshare 4.3inch DSI LCD | Larger medical-grade capacitive touch interface. | electrical | display | 1 | 45.00 | 45.00 | https://www.waveshare.com/4.3inch-dsi-lcd.htm
Printer Internal Bracket | 3D Printed Printer Mount |  | mechanical | 3d_printed | 1 | 2.50 | 2.50
Sample Scale Plate | 3D Printed Scale Plate |  | mechanical | 3d_printed | 1 | 1.50 | 1.50
N20 DC Gear Motor with Encoder | GA12-N20 DC Gear Motor 6V 200RPM with Hall Encoder | Compact DC motor with integrated quadrature encoder for position feedback. | electrical | actuator | 1 | 8.50 | 8.50 | https://www.amazon.com/s?k=N20+motor+encoder+6V
Mini H-Bridge Motor Driver | MX1508 Dual DC Motor Driver | Small dual-channel H-bridge for controlling DC motor direction and speed. | electrical | module | 1 | 2.00 | 2.00 | https://www.amazon.com/s?k=MX1508+motor+driver
N20 Motor Bracket | N20 Motor Mounting Bracket | 3D-printed adapter to mount the N20 motor to the existing chassis base. | mechanical | 3d_printed | 1 | 0.50 | 0.50 | https://www.amazon.com/s?k=N20+motor+bracket

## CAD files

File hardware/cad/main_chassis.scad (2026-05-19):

/*
 * Urine Analyzer Lite — Main Enclosure & Optical Assembly
 * Levram Lifesciences
 *
 * Modules:
 *   chassis_base()        — main shell with motor tray, PCB stand-offs
 *   optical_chamber()     — light-tight black chamber for LED + TCS34725 pair
 *   dipstick_tray()       — single-strip 6mm channel with acrylic guard slot
 *   mcu_tray()            — snap-fit bracket for ESP32-S3-DevKitC-1
 *   printer_bracket()     — mount for CSN-A2 thermal printer
 *   display_bezel()       — front panel with 4.3" LCD cutout
 *   uvc_shield()          — internal UV-C LED shroud
 *   belt_tensioner()      — adjustable GT2 belt idler arm
 *   limit_switch_bracket() — adjustable KW12-3 mount (use for home + end)
 *
 * Print settings:
 *   chassis_base, mcu_tray, dipstick_tray → PLA, 20% infill, 0.2mm layer
 *   optical_chamber, uvc_shield           → Black PLA, 100% infill, 0.1mm
 *   sensor mounts, printer_bracket        → PETG, 30% infill, 0.2mm, 4 perimeters
 */

// ── Global parameters ─────────────────────────────────────────────────────────
$fn = 48;

WALL   = 2.0;    // shell wall thickness
SCREW  = 3.2;    // M3 clearance hole diameter
INSERT = 4.2;    // M3 heat-set insert hole diameter
DRAFT  = 2;      // 2° draft for injection-mould compatibility

// ── Utility ───────────────────────────────────────────────────────────────────
module m3_hole(h=10)       { cylinder(d=SCREW,  h=h+1, center=false); }
module m3_insert(h=6)      { cylinder(d=INSERT, h=h,   center=false); }
module standoff(h=5, d=6)  { difference() { cylinder(d=d, h=h); m3_hole(h=h); } }
module fillet_cube(x,y,z,r=1) {
    minkowski() { cube([x-2*r, y-2*r, z], center=false); cylinder(r=r, h=0.01); }
}

// ── Chassis base ─────────────────────────────────────────────────────────────
module chassis_base() {
    W=160; D=120; H=55;
    difference() {
        // outer shell
        fillet_cube(W, D, H, r=3);
        // inner pocket
        translate([WALL, WALL, WALL])
            cube([W-2*WALL, D-2*WALL, H]);
        // strip tray slot on top front
        translate([25, D-30, H-WALL-0.1])
            cube([110, 20, WALL+1]);
        // USB-C cutout on right side
        translate([W-WALL-0.1, 50, 10])
            cube([WALL+1, 12, 8]);
        // display cutout on front
        translate([15, -0.1, 15])
            cube([130, WALL+1, 40]);
    }
    // PCB stand-offs (4×)
    for(pos=[[10,10],[10,D-22],[W-16,10],[W-16,D-22]])
        translate([pos[0], pos[1], WALL])
            standoff(h=8);
    // motor mount slot
    translate([W/2-20, 15, WALL])
        cube([40, 15, 6]);
}

// ── Optical chamber ──────────────────────────────────────────────────────────
module optical_chamber() {
    OW=65; OD=30; OH=45;
    difference() {
        cube([OW, OD, OH]);
        // sensor cavity (2× TCS34725 side by side, 10mm apart)
        for(sx=[5, 30])
            translate([sx, OD-12, OH-18])
                cube([20, 12+1, 18+1]);
        // LED window with diffuser slot
        translate([5, -0.1, 5])
            cube([OW-10, 6, OH-10]);
        translate([5, 4, 5])          // 2mm diffuser slot
            cube([OW-10, 2.1, OH-10]);
        // cable routing channel
        translate([OW-8, 5, 5])
            cube([6, OD-10, OH-10]);
        // M3 insert pockets (4 corners)
        for(pos=[[3,3],[3,OD-7],[OW-7,3],[OW-7,OD-7]])
            translate([pos[0], pos[1], 0])
                m3_insert(h=6);
    }
}

// ── Dipstick tray ─────────────────────────────────────────────────────────────
module dipstick_tray() {
    TW=120; TD=18; TH=8;
    difference() {
        cube([TW, TD, TH]);
        // 6mm channel for single reagent strip
        translate([5, (TD-6)/2, 2])
            cube([TW-10, 6, TH]);
        // acrylic guard slot (2mm deep, 2mm thick)
        translate([5, (TD-10)/2, TH-2])
            cube([TW-10, 10, 2.1]);
        // filter paper retainer ribs (leave 2mm every 15mm)
        for(i=[0:7])
            translate([5+i*15, (TD-6)/2, 0])
                cube([2, 6, 2]);
    }
    // end wall
    translate([TW-5, 0, 0]) cube([5, TD, TH]);
}

// ── MCU tray ──────────────────────────────────────────────────────────────────
module mcu_tray() {
    // ESP32-S3-DevKitC-1 footprint: 68.6 × 28.8mm, 2.1mm holes on 58.4×17.8mm
    BRDW=69; BRDD=29; TH=4;
    W2=BRDW+4; D2=BRDD+4;
    difference() {
        cube([W2, D2, TH]);
        // board pocket (0.5mm clearance)
        translate([2, 2, 1]) cube([BRDW, BRDD, TH]);
        // M3 mounting holes (4 corners)
        for(pos=[[0,0],[W2-5,0],[0,D2-5],[W2-5,D2-5]])
            translate([pos[0]+2.5, pos[1]+2.5, 0])
                m3_hole(h=TH);
    }
    // snap clips on long edges
    for(x=[15, W2-20])
        translate([x, D2, TH-2])
            cube([5, 3, 4]);
}

// ── Printer bracket ──────────────────────────────────────────────────────────
module printer_bracket() {
    // CSN-A2: 57.5mm wide, 37mm tall, 40mm deep
    PW=58; PD=40; PH=37;
    BWALL=2.5;
    difference() {
        cube([PW+2*BWALL, PD+BWALL, PH+BWALL]);
        translate([BWALL, 0, BWALL]) cube([PW, PD+1, PH]);
        // paper exit slot (top)
        translate([BWALL+5, PD-5, PH-5])
            cube([PW-10, BWALL+6, 5+1]);
        // USB access cutout (bottom rear)
        translate([BWALL+20, PD-6, 0])
            cube([18, BWALL+7, 10]);
        // 4× M3 mounting holes
        for(pos=[[3,5],[3,PD-5],[PW+BWALL-3,5],[PW+BWALL-3,PD-5]])
            translate([pos[0], pos[1], 0])
                m3_hole(h=PH);
    }
}

// ── Display bezel ─────────────────────────────────────────────────────────────
module display_bezel() {
    // Waveshare 4.3in DSI: 105 × 67mm active area
    BW=135; BH=80; BD=4;
    difference() {
        cube([BW, BH, BD]);
        // viewport
        translate([15, 7, -0.1]) cube([105, 66, BD+0.2]);
        // M3 holes (4 corners of bezel)
        for(pos=[[5,5],[5,BH-8],[BW-8,5],[BW-8,BH-8]])
            translate([pos[0], pos[1], 0])
                m3_hole(h=BD);
    }
}

// ── UV-C safety shroud ───────────────────────────────────────────────────────
module uvc_shield() {
    SW=30; SD=25; SH=20;
    difference() {
        cube([SW, SD, SH]);
        translate([WALL, WALL, WALL]) cube([SW-2*WALL, SD-2*WALL, SH]);
        // LED pocket top
        translate([SW/2-5, SD/2-5, 0]) cube([10, 10, 5]);
        // aluminium strip channel on face (for reflector)
        translate([-0.1, SD/2-2, 5]) cube([WALL+0.2, 4, SH-10]);
    }
}

// ── Belt tensioner ────────────────────────────────────────────────────────────
module belt_tensioner() {
    difference() {
        union() {
            cube([30, 12, 6]);
            translate([25, 6, 0]) cylinder(d=12, h=6);  // idler hub
        }
        // Idler bearing hole (625ZZ: 5mm ID)
        translate([25, 6, -0.1]) cylinder(d=5.1, h=6+0.2);
        // Slot for adjustment (4mm wide, 15mm long)
        translate([4, 4, -0.1]) cube([15, 4, 6+0.2]);
        // M3 bolt through slot
        translate([11, 6, -0.1]) m3_hole(h=6);
    }
}

// ── Limit switch bracket ──────────────────────────────────────────────────────
module limit_switch_bracket() {
    // KW12-3: 20×10×6mm body, 2×M2.5 at 9.5mm spacing
    difference() {
        cube([30, 18, 8]);
        // switch pocket
        translate([5, 4, 2]) cube([20, 10, 6+1]);
        // M2.5 mounting holes
        for(sx=[9, 18.5])
            translate([sx, 9, -0.1]) cylinder(d=2.7, h=8+0.2);
        // M3 chassis mount slot
        translate([0, 7, 4]) rotate([0, 90, 0])
            hull() {
                cylinder(d=SCREW, h=8);
                translate([0, 0, 20]) cylinder(d=SCREW, h=8);
            }
    }
}

// ── Render all parts spaced on build plate ────────────────────────────────────
translate([0,   0,  0])  chassis_base();
translate([170, 0,  0])  optical_chamber();
translate([170, 50, 0])  dipstick_tray();
translate([0,   130,0])  mcu_tray();
translate([80,  130,0])  printer_bracket();
translate([0,   170,0])  display_bezel();
translate([170, 90, 0])  uvc_shield();
translate([220, 90, 0])  belt_tensioner();
translate([260, 90, 0])  limit_switch_bracket();

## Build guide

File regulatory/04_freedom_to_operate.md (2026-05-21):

# Freedom-to-Operate (FTO) — Preliminary Search — Urine Analyzer Lite

> Stage 0 Foundation document. Status: PRELIMINARY (2026-05-21).
> Scope: the **optical reading mechanism** (stated novelty: optics/hardware).
> **This is a self-service preliminary search, NOT a legal opinion.** Before commercial
> launch, commission a formal FTO/clearance search from a patent attorney, especially for
> any export market (US/EU).

## 1. Why this matters here
The stated competitive edge is "optics / hardware." That is exactly the area where this
device category is **most heavily patented**, so FTO risk is concentrated in the novelty.
Reflectance photometry of urine strips is a mature field (commercial readers since the
1980s — Bayer/Siemens Clinitek, Roche Urisys, etc.), so the *fundamental* reading method is
old and largely in the public domain / expired. Risk lives in **specific recent
implementations**: multi-wavelength imaging, interference correction, algorithmic
classification, and integrated sample/strip handling.

## 2. Search performed (2026-05-21)
Web/patent searches via Google Patents, Justia, and literature. Recommended next:
re-run on **Google Patents, Lens.org, Espacenet** with CPC class **G01N 33/493** (urine
analysis) and **G01N 21/25/.../78** (colorimetry/reflectance), plus full INPADOC family +
legal-status (expiry) checks.

Queries used: `optical reflectance urine reagent strip reader colorimetric automated`;
`urinalysis dipstick reader RGB color sensor strip transport`.

## 3. Patents/applications identified (preliminary — verify status & claims)

| Ref | Title | Relevance | Action needed |
|---|---|---|---|
| **US11307147B2** | Accurate colorimetric based test-strip reader system | Illuminate strip w/ selected spectra, capture images, compare to calibration curves, **correct for interference** | Read claims; our interference handling must avoid claimed method; check legal status & jurisdiction |
| **US20200124587 (A1)** | Urinalysis device and test strip for home & POC use | Multi-LED (R/G/B/White/Orange/IR/UV); per-pad image combinations by chemistry; integrated sample loading | Check if granted & claims; our single white-CRI-LED + RGB-sensor approach likely differs, but verify the UV/multi-wavelength angle |
| **KR20110042691A** | Portable Urine Analyzer | LED white source + **color-sensor array** + strip loader — closest architectural match to our TCS34725 + LED + motorized loader | Check status/family; likely older — possibly expired/abandoned (favorable if so) |
| **US20120208288A1** | Unitized point-of-care urine dipstick control device | POC dipstick handling/QC | Lower direct relevance; review |

## 4. Preliminary risk read
- **Core reflectance reading (white LED illuminates pad → RGB/color sensor → classify):**
  LOW FTO risk — decades-old, well-documented, foundational patents expired.
- **Specific algorithmic claims** (e.g. interference correction à la US11307147B2,
  multi-wavelength image combination à la US20200124587): MEDIUM — must read claims and
  design around; do not copy a claimed multi-spectral interference-correction method.
- **Integrated sample-loading / strip-transport mechanisms:** MEDIUM — several patents cover
  loaders; our N20 motorized tray should be checked against KR20110042691A and similar.
- **UV-C sterilization within a urine reader:** appears uncommon — possible novelty *and*
  possible standalone IP, but also the biggest safety/regulatory cost (see risk file H1).

## 5. Implications for the "optics is our novelty" strategy
Honest assessment: a white-LED + commodity RGB-sensor (TCS34725) reflectance head is **not
novel** on its own — it is the textbook approach and is already in the prior art (incl.
KR20110042691A). To make "optics/hardware" a real differentiator (and patentable), the edge
likely needs to be something more specific, e.g.:
- a genuinely better illumination/optical geometry that improves accuracy or cost,
- multi-angle / dual-sensor differential reading that demonstrably reduces a known error source,
- a self-calibration / ambient-compensation scheme that is novel and provable.
Recommend deciding *what specifically* is novel, then doing a focused FTO + a possible
provisional patent filing around that, rather than around "an optical urine reader" generally.

## 6. Next actions
- [ ] Re-run searches on Lens.org + Espacenet with CPC G01N33/493 & G01N21; pull INPADOC families.
- [ ] Check **legal status / expiry / jurisdiction** of each patent above (esp. India designations).
- [ ] Read the independent claims of US11307147B2 and US20200124587; document design-arounds.
- [ ] Define the specific, defensible optical novelty (see §5) → consider provisional filing.
- [ ] Commission formal attorney FTO before commercial launch / fundraising / export.

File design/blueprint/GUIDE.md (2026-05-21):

## Tools
- Soldering iron with fine tip
- M3 and M2.5 hex keys
- Heat-set insert installation tool (soldering iron tip)
- Wire strippers and crimpers
- 3D printer (PLA and PETG capable)
- Multimeter
- Precision screwdriver set
- Acrylic glue or adhesive gaskets

## Assumptions
- Access to a 3D printer for manufacturing structural components
- Familiarity with ESP32-S3 firmware flashing and I2C debugging
- Basic soldering skills for small-pitch modules
- All 3D prints are cleaned and deburred prior to assembly

## 1. Fabrication
### 1.1 Print optical chamber components in black PLA
*(not yet generated)*

### 1.2 Print sensor and actuator mounts in PETG
*(not yet generated)*

### 1.3 Install heat-set inserts into optical chamber
*(not yet generated)*

### 1.4 Cut and prepare acrylic flattening guard and diffuser
*(not yet generated)*

### 1.5 Print chassis base and tray components
*(not yet generated)*

## 2. Wiring
### 2.1 Connect LiPo battery to charging and regulation circuit
*(not yet generated)*

### 2.2 Solder I2C bus harness for sensors and ADC
*(not yet generated)*

### 2.3 Wire N20 motor and encoder to H-bridge driver
*(not yet generated)*

### 2.4 Connect high-power LEDs and MOSFET driver
*(not yet generated)*

### 2.5 Wire thermal printer and load cell to MCU
*(not yet generated)*

### 2.6 Connect display and start button to system controller
*(not yet generated)*

## 3. Bring-up
### 3.1 Verify power rail voltages (3.3V, 5V, 9V)
*(not yet generated)*

### 3.2 Scan I2C bus for all sensor addresses
*(not yet generated)*

### 3.3 Test motor movement and limit switch logic
*(not yet generated)*

### 3.4 Calibrate RGB sensors using white standard
*(not yet generated)*

### 3.5 Validate weight sensor and printer communication
*(not yet generated)*

## 4. Assembly
### 4.1 Mount N20 motor and belt drive system to chassis
*(not yet generated)*

### 4.2 Assemble optical chamber with LEDs and sensors
*(not yet generated)*

### 4.3 Install strip tray and calibration target
*(not yet generated)*

### 4.4 Secure MCU tray and printer to housing
*(not yet generated)*

### 4.5 Install display and final enclosure shell
*(not yet generated)*

### 4.6 Final system test and liner placement
*(not yet generated)*

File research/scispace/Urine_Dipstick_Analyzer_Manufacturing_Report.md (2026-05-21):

# Design and Manufacturing Guide for Economical Urine Dipstick Analyzer (2P and 10P) for the Indian Market

**A Comprehensive Technical Report**

**Date:** May 15, 2026

**Target Market:** Indian Healthcare Distribution Network

**Benchmark Systems:** Siemens Clinitek Status+ and Mission U120

---

## Executive Summary

This report provides a comprehensive technical blueprint for designing, manufacturing, and commercializing an economical benchtop urine dipstick analyzer for the Indian market. The analyzer will support both 2-parameter (2P) and 10-parameter (10P) test strips using reflectance photometry technology. Based on extensive analysis of 78 peer-reviewed papers and industry benchmarks (Siemens Clinitek and Mission analyzers), this report details the complete technology stack, bill of materials (BOM), electronics architecture, optical design, manufacturing processes, regulatory requirements, and cost optimization strategies. The proposed design leverages proven technologies—LED-based multispectral illumination, optical fiber coupling, 32-bit microcontroller control, and automated calibration algorithms—to deliver clinical-grade performance at a competitive price point suitable for Indian clinics, diagnostic centers, and hospitals. Key design principles emphasize modularity (2P to 10P scalability), use of readily available components, simplified assembly processes, and compliance with Indian CDSCO regulations for Class B/C in-vitro diagnostic (IVD) devices.

---

## Table of Contents

1. [Introduction](#1-introduction)
2. [Technology Overview](#2-technology-overview)
3. [System Architecture](#3-system-architecture)
4. [Optical Design](#4-optical-design)
5. [Electronics and Control System](#5-electronics-and-control-system)
6. [Bill of Materials (BOM)](#6-bill-of-materials-bom)
7. [Signal Processing and Calibration Algorithms](#7-signal-processing-and-calibration-algorithms)
8. [Mechanical Design and Enclosure](#8-mechanical-design-and-enclosure)
9. [Manufacturing Process](#9-manufacturing-process)
10. [Quality Control and Testing](#10-quality-control-and-testing)
11. [Regulatory Requirements for Indian Market](#11-regulatory-requirements-for-indian-market)
12. [Cost Analysis and Pricing Strategy](#12-cost-analysis-and-pricing-strategy)
13. [Benchmark Comparison](#13-benchmark-comparison)
14. [Infrastructure and Know-How Requirements](#14-infrastructure-and-know-how-requirements)
15. [Future Directions and Scalability](#15-future-directions-and-scalability)
16. [Conclusion](#16-conclusion)
17. [References](#17-references)

---

## 1. Introduction

### 1.1 Background

Urinalysis is a fundamental diagnostic tool used worldwide for screening and monitoring renal diseases, diabetes, urinary tract infections, and metabolic disorders. Urine test strips (dipsticks) provide rapid, cost-effective semiquantitative analysis of multiple parameters including glucose, protein, pH, specific gravity, ketones, bilirubin, urobilinogen, blood, nitrite, and leukocytes [1]. While visual interpretation of dipsticks is common in resource-limited settings, automated analyzers offer superior accuracy, reproducibility, and throughput by eliminating subjective color interpretation [2], [3].

### 1.2 Market Opportunity in India

The Indian in-vitro diagnostics (IVD) market is experiencing rapid growth driven by increasing healthcare awareness, rising chronic disease prevalence, and expanding diagnostic infrastructure. Urine analyzers represent a significant segment, with demand from hospitals, diagnostic laboratories, primary health centers, and private clinics. However, imported high-end analyzers (Siemens Clinitek Status+, Roche Cobas, Sysmex UC series) are often cost-prohibitive for smaller facilities. An economical, locally manufactured or assembled analyzer can capture substantial market share through existing distribution networks.

### 1.3 Objectives

This report aims to provide:

- Complete technical specifications for 2P and 10P urine dipstick analyzers
- Detailed optical and electronic design with component-level BOM
- Manufacturing processes suitable for small to medium-scale production
- Regulatory compliance roadmap for CDSCO approval
- Cost optimization strategies to achieve competitive pricing
- Infrastructure and expertise requirements for in-house manufacturing

---

## 2. Technology Overview

### 2.1 Measurement Principle: Reflectance Photometry

Urine dipstick analyzers operate on the principle of **reflectance photometry**, where reagent pads on the test strip undergo colorimetric reactions upon contact with urine. The analyzer measures the intensity of light reflected from each pad under controlled illumination and correlates these reflectance values to analyte concentrations [4], [5]. This method has been validated against quantitative reference assays and demonstrates strong correlations for glucose, protein, and other analytes [6].

### 2.2 Key Technology Components

Modern benchtop analyzers integrate four core subsystems [7], [8]:

1. **Optical System:** Light source (LEDs), optical path (fibers or direct), photodetectors, and geometry control
2. **Electronics:** Microcontroller, analog front-end (transimpedance amplifiers, ADC), power management, and communication interfaces
3. **Mechanical System:** Strip insertion mechanism, positioning guides, enclosure, and thermal management
4. **Software:** Signal processing algorithms, calibration routines, user interface, and data management

### 2.3 2P vs. 10P Design Considerations

| Feature | 2-Parameter (2P) | 10-Parameter (10P) |
|---|---|---|
| **Complexity** | Simpler optical path, fewer LEDs/detectors | Multi-wavelength illumination, scanning or multiple detectors |
| **Calibration** | Single or dual-channel calibration | Per-analyte multilevel calibration curves |
| **Throughput** | Manual insertion, lower volume | Potential for semi-automated handling |
| **Cost** | Lower component count, simplified assembly | Higher MCU performance, more ADC channels |
| **Target Market** | Small clinics, point-of-care | Diagnostic labs, hospitals |

Both configurations share the same core architecture, enabling modular scalability [9].

---

## 3. System Architecture

### 3.1 Functional Block Diagram

```
┌─────────────────────────────────────────────────────────────┐
│                    URINE DIPSTICK ANALYZER                  │
├─────────────────────────────────────────────────────────────┤
│                                                             │
│  ┌──────────────┐      ┌──────────────┐                   │
│  │  Strip       │      │  Optical     │                   │
│  │  Insertion   │─────▶│  Measurement │                   │
│  │  Mechanism   │      │  Chamber     │                   │
│  └──────────────┘      └──────┬───────┘                   │
│                               │                            │
│                               ▼                            │
│  ┌──────────────────────────────────────────────────┐     │
│  │         OPTICAL SUBSYSTEM                        │     │
│  │  ┌──────────┐  ┌──────────┐  ┌──────────┐      │     │
│  │  │ LED      │  │ Optical  │  │ Photo-   │      │     │
│  │  │ Array    │─▶│ Fibers   │─▶│ detectors│      │     │
│  │  │ (RGB/W)  │  │          │  │ (Si PD)  │      │     │
│  │  └──────────┘  └──────────┘  └────┬─────┘      │     │
│  │                                    │            │     │
│  │  ┌──────────────────────────────────┘            │     │
│  │  │  Temperature Sensor                          │     │
│  │  └──────────────────────────────────┐            │     │
│  └───────────────────────────────────┬─┘            │     │
│                                      │              │     │
│                                      ▼              │     │
│  ┌──────────────────────────────────────────────────┐     │
│  │      ELECTRONICS & CONTROL SUBSYSTEM             │     │
│  │  ┌──────────────┐  ┌──────────────┐            │     │
│  │  │ Transimpedance│  │ Precision    │            │     │
│  │  │ Amplifiers   │─▶│ ADC          │            │     │
│  │  └──────────────┘  └──────┬───────┘            │     │
│  │                           │                     │     │
│  │  ┌────────────────────────▼──────────────┐     │     │
│  │  │  32-bit Microcontroller (STM32)       │     │     │
│  │  │  - Signal Processing                  │     │     │
│  │  │  - Calibration Algorithms             │     │     │
│  │  │  - User Interface Control             │     │     │
│  │  └────────────┬──────────────────────────┘     │     │
│  │               │                                 │     │
│  │  ┌────────────▼──────────┐  ┌──────────────┐  │     │
│  │  │ Display (LCD/OLED)    │  │ USB/WiFi     │  │     │
│  │  │ & Keypad              │  │ Interface    │  │     │
│  │  └───────────────────────┘  └──────────────┘  │     │
│  └──────────────────────────────────────────────────┘     │
│                                                             │
│  ┌──────────────────────────────────────────────────┐     │
│  │         POWER MANAGEMENT                         │     │
│  │  AC/DC Adapter → Voltage Regulators → Components│     │
│  └──────────────────────────────────────────────────┘     │
└─────────────────────────────────────────────────────────────┘
```

### 3.2 Operational Workflow

1. **Strip Insertion:** User inserts dipped test strip into measurement chamber
2. **Positioning:** Mechanical guides ensure consistent strip placement and distance
3. **Illumination:** LED array activates with controlled intensity
4. **Detection:** Photodetectors measure reflected light from each reagent pad
5. **Signal Processing:** MCU performs dark subtraction, ratioing, temperature compensation
6. **Calibration Mapping:** Reflectance values mapped to semiquantitative categories via lookup tables
7. **Display & Output:** Results displayed on screen and transmitted via USB/WiFi
8. **Quality Control:** Internal reference checks and error detection

---

## 4. Optical Design

### 4.1 Design Philosophy

The optical subsystem must deliver stable, reproducible reflectance measurements across varying environmental conditions and strip placement tolerances. Key design goals include [10], [11]:

- **Spectral coverage:** Broad spectrum (400-700 nm) to accommodate diverse reagent chemistries
- **Geometry control:** Fixed illumination/detection angles to minimize distance-dependent errors
- **Ambient light rejection:** Optical isolation to prevent interference
- **Thermal stability:** Compensation for LED intensity drift with temperature

### 4.2 Light Source Selection

#### 4.2.1 Tri-Chromatic LED Configuration (Recommended for 10P)

A composite light source using red, green, and blue (RGB) LEDs provides multispectral illumination covering the visible spectrum [12], [13]. This approach enables:

- **Wavelength specificity:** Different reagent pads absorb optimally at different wavelengths
- **Intensity control:** Individual LED brightness adjustment via PWM for dynamic range optimization
- **Cost-effectiveness:** Standard RGB LEDs are widely available and inexpensive

**Recommended Component:**
- **Part:** Cree CLVBA-FKA or equivalent tri-color LED
- **Specifications:** Red (620-630 nm), Green (520-535 nm), Blue (460-475 nm)
- **Forward Current:** 20 mA per color
- **Viewing Angle:** 120° for uniform illumination

#### 4.2.2 White LED Configuration (Alternative for 2P)

For simplified 2P systems, a single high-CRI (Color Rendering Index > 90) white LED can suffice [14]:

- **Part:** Nichia NFSW757G-V1 or Lumileds LUXEON 3535L
- **CCT:** 5000-6500K (daylight equivalent)
- **Luminous Flux:** 100-150 lm
- **Advantage:** Simpler driver circuit, lower cost

### 4.3 Optical Path Architecture

#### 4.3.1 Fiber-Optic Coupling (Recommended)

Optical fiber bundles offer significant advantages for manufacturing tolerances and measurement stability [15], [16]:

**Configuration:**
1. **Illumination Fibers:** Bundle of 6-12 plastic optical fibers (POF) transmit LED light to strip surface
2. **Collection Fibers:** Separate bundle collects reflected light and routes to photodetector
3. **Reference Channel:** Additional fiber directly couples LED to reference photodiode for intensity normalization

**Benefits:**
- Decouples LED/detector placement from measurement chamber
- Reduces sensitivity to strip distance variations (±2 mm tolerance)
- Simplifies mechanical assembly and alignment
- Blocks ambient light effectively

**Recommended Fiber:**
- **Type:** PMMA (Polymethyl Methacrylate) plastic optical fiber
- **Core Diameter:** 1 mm
- **Numerical Aperture:** 0.5
- **Length:** 50-100 mm
- **Supplier:** Mitsubishi Rayon ESKA series or equivalent

#### 4.3.2 Direct Illumination (Alternative for Cost Reduction)

For 2P systems, direct LED-to-strip illumination with collimating optics can reduce cost:

- **LED Positioning:** 45° angle to strip surface, 20-30 mm distance
- **Collimating Lens:** 10 mm diameter, f = 15 mm focal length
- **Detector Positioning:** Normal to strip surface (0° angle)
- **Ambient Light Shield:** Black ABS enclosure with light trap

### 4.4 Photodetector Selection

#### 4.4.1 Silicon Photodiodes (Primary Choice)

**For 10P System:**
- **Part:** Hamamatsu S2386-8K or OSRAM SFH 2430
- **Type:** PIN photodiode with integrated daylight filter
- **Active Area:** 7.5 mm²
- **Spectral Range:** 400-1000 nm (peak ~900 nm)
- **Responsivity:** 0.4-0.6 A/W at 550 nm
- **Quantity:** 2-3 detectors (reflected light, reference, optional ambient monitor)

**For 2P System:**
- **Part:** Vishay BPW34 or equivalent
- **Active Area:** 7.5 mm²
- **Package:** T-1 3/4 (5 mm) plastic case
- **Cost:** ~$0.50 per unit

#### 4.4.2 Color Sensors (Alternative for RGB Measurement)

For integrated RGB detection without multiple photodiodes:

- **Part:** AMS TCS3472 or Avago APDS-9960
- **Features:** 4-channel (RGB + Clear) with I²C interface
- **Advantage:** Single-chip solution, digital output
- **Disadvantage:** Lower sensitivity than discrete photodiodes

### 4.5 Distance Control and Positioning

To maintain consistent measurement geometry [17]:

1. **Mechanical Guides:** Precision-molded ABS guides with ±0.5 mm tolerance
2. **Spring-Loaded Platen:** Gentle pressure ensures strip flatness against measurement window
3. **Optical Triangulation (Optional):** Non-contact distance sensor (e.g., Sharp GP2Y0A21YK) for active distance monitoring and correction

---

## 5. Electronics and Control System

### 5.1 Microcontroller Selection

#### 5.1.1 Recommended MCU: STM32F103 Series

The STM32F103VE (or equivalent) provides optimal balance of performance, peripherals, and cost [18], [19]:

**Specifications:**
- **Core:** ARM Cortex-M3, 72 MHz
- **Flash:** 512 KB (sufficient for calibration tables and firmware)
- **RAM:** 64 KB
- **ADC:** 3× 12-bit ADC, 1 µs conversion time, 16 channels
- **Timers:** Multiple 16-bit timers for PWM LED control
- **Communication:** USB 2.0, UART, SPI, I²C
- **Package:** LQFP100 (14×14 mm)
- **Cost:** ~$3-5 per unit (bulk)
- **Availability:** Widely available in India through distributors

**Alternative (Budget Option):**
- **STM32F030C8T6:** Cortex-M0, 48 MHz, 64 KB Flash, $1-2 per unit
- **Trade-off:** Reduced processing power, fewer peripherals

### 5.2 Analog Front-End Design

#### 5.2.1 Photodiode Signal Conditioning

Each photodiode requires a transimpedance amplifier (TIA) to convert photocurrent to voltage [20]:

**Circuit Configuration:**

```
Photodiode (Reverse Bias) → TIA → Low-Pass Filter → ADC Input
```

**Recommended Op-Amp:**
- **Part:** Texas Instruments OPA2365 (dual op-amp)
- **Features:** Rail-to-rail I/O, 50 MHz GBW, low noise (6 nV/√Hz)
- **Gain Resistor:** 100 kΩ - 1 MΩ (adjustable based on light intensity)
- **Feedback Capacitor:** 10-22 pF (bandwidth limiting)

**Low-Pass Filter:**
- **Cutoff Frequency:** 1-10 kHz (removes high-frequency noise)
- **Topology:** 2nd-order Sallen-Key or simple RC

#### 5.2.2 Precision Voltage Reference

Critical for ADC accuracy and repeatability [21]:

- **Part:** Texas Instruments LM4132A-3.0 or Analog Devices ADR4530
- **Output Voltage:** 3.0 V (matches ADC reference input)
- **Initial Accuracy:** ±0.1% (3 mV)
- **Temperature Coefficient:** 10 ppm/°C
- **Load Regulation:** 10 ppm/mA
- **Cost:** ~$1-2 per unit

### 5.3 LED Driver Circuit

#### 5.3.1 Constant Current Driver

To ensure stable LED intensity independent of supply voltage variations:

**For Each LED Color:**
- **Driver IC:** Texas Instruments TLC5940 (16-channel PWM LED driver) or discrete constant-current source
- **Current Setting:** 10-20 mA per LED (via external resistor)
- **PWM Control:** 12-bit resolution for intensity adjustment (0-100%)
- **Dimming Frequency:** 1-10 kHz (above flicker fusion threshold)

**Discrete Alternative (Lower Cost):**
- **Transistor:** 2N3904 NPN or equivalent
- **Current Sense Resistor:** 100-220 Ω
- **PWM from MCU:** Timer output (TIM2/TIM3 on STM32)

### 5.4 Temperature Sensing

Temperature compensation is essential for accurate reflectance measurements [22]:

- **Sensor:** NTC thermistor (10 kΩ at 25°C, B = 3950) or digital sensor (DS18B20)
- **Placement:** Near LED array and measurement chamber
- **Interface:** ADC input (thermistor) or 1-Wire (DS18B20)
- **Compensation Algorithm:** Linear or polynomial correction applied to reflectance values

### 5.5 Power Supply Design

#### 5.5.1 Input Power

- **AC/DC Adapter:** 12V, 1A (12W) medical-grade adapter (IEC 60601-1 compliant)
- **Connector:** 2.1 mm barrel jack or IEC C14 inlet

#### 5.5.2 Voltage Regulation

Multiple regulated rails required:

| Rail | Voltage | Current | Regulator | Application |
|---|---|---|---|---|
| Digital | 3.3V | 500 mA | LM1117-3.3 | MCU, logic |
| Analog | 3.3V | 200 mA | LM1117-3.3 (separate) | ADC, op-amps |
| LED | 5V | 300 mA | LM7805 or buck converter | LED drivers |
| Display | 5V | 200 mA | Shared with LED | LCD backlight |

**Key Design Principles:**
- **Separate Analog/Digital Grounds:** Star grounding topology to minimize noise coupling
- **Decoupling Capacitors:** 100 nF ceramic + 10 µF electrolytic at each IC
- **Ferrite Beads:** Isolate analog power rail from digital switching noise

### 5.6 Communication Interfaces

#### 5.6.1 USB Interface (Standard)

- **Controller:** Built-in USB 2.0 Full-Speed (12 Mbps) on STM32F103
- **Protocol:** USB CDC (Virtual COM Port) for easy PC connectivity
- **Connector:** USB Type-B or Micro-USB
- **Function:** Result export, firmware updates, configuration

#### 5.6.2 WiFi Module (Optional for 10P)

- **Module:** ESP8266 (ESP-01) or ESP32-WROOM-32
- **Interface:** UART (115200 baud)
- **Protocol:** MQTT or HTTP for cloud connectivity
- **Cost:** ~$2-3 per module
- **Application:** Remote monitoring, LIS integration

#### 5.6.3 Display Interface

**For 2P System:**
- **Display:** 16×2 character LCD (HD44780 compatible)
- **Interface:** 4-bit parallel or I²C (PCF8574 expander)
- **Cost:** ~$2-3

**For 10P System:**
- **Display:** 2.8" TFT LCD (320×240 pixels, ILI9341 controller)
- **Interface:** SPI (4-wire)
- **Touchscreen:** Resistive or capacitive (optional)
- **Cost:** ~$8-12

---

## 6. Bill of Materials (BOM)

### 6.1 Complete BOM for 2-Parameter (2P) Analyzer

| Category | Component | Part Number / Spec | Qty | Unit Cost (USD) | Total Cost (USD) | Supplier |
|---|---|---|-----|---|---|---|
| **Optical** | White LED | Nichia NFSW757G | 1 | 0.50 | 0.50 | Digi-Key, Mouser |
| | Photodiode | Vishay BPW34 | 2 | 0.50 | 1.00 | Digi-Key, Mouser |
| | Plastic Optical Fiber | PMMA, 1mm, 1m | 1 | 5.00 | 5.00 | Mitsubishi, local |
| | Collimating Lens | 10mm dia, f=15mm | 2 | 1.00 | 2.00 | Edmund Optics |
| **Electronics** | Microcontroller | STM32F030C8T6 | 1 | 1.50 | 1.50 | ST Micro, local |
| | Op-Amp (Dual) | OPA2365AIDR | 1 | 1.20 | 1.20 | TI, Mouser |
| | Voltage Reference | LM4132A-3.0 | 1 | 1.50 | 1.50 | TI, Mouser |
| | Voltage Regulator | LM1117-3.3 | 2 | 0.30 | 0.60 | Local |
| | LED Driver Transistor | 2N3904 | 1 | 0.05 | 0.05 | Local |
| | Temperature Sensor | NTC 10K thermistor | 1 | 0.20 | 0.20 | Local |
| | Resistors (assorted) | 0805 SMD, 1% | 50 | 0.01 | 0.50 | Local |
| | Capacitors (assorted) | 0805 SMD, ceramic | 30 | 0.02 | 0.60 | Local |
| | Electrolytic Caps | 10µF, 100µF, 16V | 5 | 0.10 | 0.50 | Local |
| | PCB (2-layer) | FR-4, 100×80 mm | 1 | 3.00 | 3.00 | Local PCB fab |
| **Display & I/O** | LCD Display | 16×2 character, I²C | 1 | 2.50 | 2.50 | Local |
| | Push Buttons | Tactile, 6×6 mm | 4 | 0.10 | 0.40 | Local |
| | USB Connector | Micro-USB Type-B | 1 | 0.30 | 0.30 | Local |
| **Mechanical** | Enclosure | ABS plastic, molded | 1 | 5.00 | 5.00 | Local injection |
| | Strip Guide | ABS, precision molded | 1 | 1.00 | 1.00 | Local |
| | Measurement Window | Acrylic, 3mm, 30×10mm | 1 | 0.50 | 0.50 | Local |
| | Screws & Hardware | M3 screws, standoffs | 1 set | 0.50 | 0.50 | Local |
| **Power** | AC/DC Adapter | 12V, 1A, medical grade | 1 | 3.00 | 3.00 | Mean Well, local |
| | Power Jack | 2.1mm barrel | 1 | 0.20 | 0.20 | Local |
| **Miscellaneous** | Cables & Connectors | USB cable, wires | 1 set | 1.00 | 1.00 | Local |
| | Thermal Pads | Silicone, 1mm | 1 | 0.50 | 0.50 | Local |
| | Labels & Stickers | Product branding | 1 set | 0.50 | 0.50 | Local printing |
| **TOTAL** | | | | | **$33.55** | |

**Notes:**
- Costs are approximate bulk pricing (100-1000 units)
- Local suppliers in India (Mumbai, Delhi, Bangalore electronics markets) offer competitive pricing
- Add 20-30% for assembly labor, testing, packaging, and overhead
- **Estimated Manufacturing Cost:** $40-45 per unit
- **Suggested Retail Price:** ₹6,000-8,000 ($72-96) for 50-60% margin

### 6.2 Complete BOM for 10-Parameter (10P) Analyzer

| Category | Component | Part Number / Spec | Qty | Unit Cost (USD) | Total Cost (USD) | Supplier |
|---|---|---|-----|---|---|---|
| **Optical** | RGB LED | Cree CLVBA-FKA | 1 | 1.50 | 1.50 | Digi-Key, Mouser |
| | Photodiode | Hamamatsu S2386-8K | 3 | 2.00 | 6.00 | Digi-Key, Mouser |
| | Plastic Optical Fiber | PMMA, 1mm, 2m | 1 | 8.00 | 8.00 | Mitsubishi, local |
| | Collimating Lens | 10mm dia, f=15mm | 3 | 1.00 | 3.00 | Edmund Optics |
| | Distance Sensor (opt) | Sharp GP2Y0A21YK | 1 | 3.00 | 3.00 | Sharp, Mouser |
| **Electronics** | Microcontroller | STM32F103VET6 | 1 | 4.50 | 4.50 | ST Micro, local |
| | Op-Amp (Dual) | OPA2365AIDR | 2 | 1.20 | 2.40 | TI, Mouser |
| | Voltage Reference | LM4132A-3.0 | 1 | 1.50 | 1.50 | TI, Mouser |
| | Voltage Regulator | LM1117-3.3 | 3 | 0.30 | 0.90 | Local |
| | LED Driver IC | TLC5940PWP | 1 | 2.50 | 2.50 | TI, Mouser |
| | Temperature Sensor | DS18B20 (digital) | 1 | 0.80 | 0.80 | Maxim, local |
| | Resistors (assorted) | 0805 SMD, 1% | 100 | 0.01 | 1.00 | Local |
| | Capacitors (assorted) | 0805 SMD, ceramic | 60 | 0.02 | 1.20 | Local |
| | Electrolytic Caps | 10µF, 100µF, 16V | 8 | 0.10 | 0.80 | Local |
| | PCB (4-layer) | FR-4, 150×100 mm | 1 | 8.00 | 8.00 | Local PCB fab |
| **Display & I/O** | TFT LCD Display | 2.8" 320×240, ILI9341 | 1 | 10.00 | 10.00 | Local |
| | Touchscreen (opt) | Resistive, 2.8" | 1 | 3.00 | 3.00 | Local |
| | Push Buttons | Tactile, 6×6 mm | 6 | 0.10 | 0.60 | Local |
| | USB Connector | Micro-USB Type-B | 1 | 0.30 | 0.30 | Local |
| | WiFi Module (opt) | ESP8266 ESP-01 | 1 | 2.50 | 2.50 | Espressif, local |
| **Mechanical** | Enclosure | ABS plastic, molded | 1 | 12.00 | 12.00 | Local injection |
| | Strip Guide | ABS, precision molded | 1 | 2.00 | 2.00 | Local |
| | Measurement Window | Acrylic, 3mm, 50×15mm | 1 | 1.00 | 1.00 | Local |
| | Screws & Hardware | M3 screws, standoffs | 1 set | 1.00 | 1.00 | Local |
| **Power** | AC/DC Adapter | 12V, 1.5A, medical | 1 | 4.00 | 4.00 | Mean Well, local |
| | Power Jack | 2.1mm barrel | 1 | 0.20 | 0.20 | Local |
| **Miscellaneous** | Cables & Connectors | USB cable, wires | 1 set | 2.00 | 2.00 | Local |
| | Thermal Pads | Silicone, 1mm | 2 | 0.50 | 1.00 | Local |
| | Labels & Stickers | Product branding | 1 set | 1.00 | 1.00 | Local printing |
| **TOTAL** | | | | | **$84.70** | |

**Notes:**
- Costs are approximate bulk pricing (100-1000 units)
- Add 25-35% for assembly labor, testing, packaging, and overhead
- **Estimated Manufacturing Cost:** $105-115 per unit
- **Suggested Retail Price:** ₹15,000-20,000 ($180-240) for 50-60% margin

### 6.3 Component Sourcing Strategy for India

**Local Distributors:**
- **Electronics:** Lamington Road (Mumbai), Nehru Place (Delhi), SP Road (Bangalore)
- **Semiconductors:** Arrow Electronics India, Avnet India, Digi-Key/Mouser (import)
- **Optical Components:** Robu.in, Evelta Electronics, Sunrom Technologies
- **Mechanical Parts:** Local injection molding vendors, CNC machine shops

**Import Considerations:**
- **Lead Time:** 4-8 weeks for international orders
- **Customs Duty:** 10-20% on electronic components (check HSN codes)
- **Minimum Order Quantities:** Plan for 6-12 month inventory to reduce per-unit costs

---

## 7. Signal Processing and Calibration Algorithms

### 7.1 Signal Acquisition Pipeline

The raw photodiode signals undergo multi-stage processing to yield accurate reflectance values [23], [24]:

**Stage 1: Dark Current Subtraction**
```
R_corrected = R_measured - R_dark
```
Where R_dark is measured with LEDs off to account for ambient light and detector dark current.

**Stage 2: Reference Normalization**
```
R_normalized = R_corrected / R_reference
```
The reference photodiode measures direct LED intensity, compensating for source drift and temperature effects [25].

**Stage 3: Temperature Compensation**
```
R_compensated = R_normalized × (1 + α × ΔT)
```
Where α is the temperature coefficient (typically 0.001-0.003 per °C) and ΔT is deviation from calibration temperature (25°C).

### 7.2 Calibration Methods

#### 7.2.1 Two-Point Calibration (2P System)

For simple 2P analyzers measuring glucose and protein [26]:

1. **White Reference:** Measure reflectance from unused (white) pad region → R_white
2. **Colored Reference:** Measure reflectance from known concentration standard → R_standard
3. **Mapping:** Linear interpolation between R_white (negative) and R_standard (positive threshold)

**Implementation:**
```c
float glucose_concentration(float R_measured) {
    float R_norm = (R_measured - R_dark) / (R_white - R_dark);
    if (R_norm > 0.85) return 0;        // Negative
    else if (R_norm > 0.70) return 50;  // Trace (50 mg/dL)
    else if (R_norm > 0.55) return 100; // 1+ (100 mg/dL)
    else if (R_norm > 0.40) return 250; // 2+ (250 mg/dL)
    else if (R_norm > 0.25) return 500; // 3+ (500 mg/dL)
    else return 1000;                   // 4+ (≥1000 mg/dL)
}
```

#### 7.2.2 Multilevel Calibration (10P System)

For accurate quantification across multiple analytes [27]:

1. **Calibration Strip Set:** Prepare strips with known concentrations (e.g., 5 levels per analyte)
2. **Spectral Measurement:** Measure reflectance at multiple wavelengths (R, G, B channels)
3. **Curve Fitting:** Polynomial or logarithmic regression:
   ```
   Concentration = a₀ + a₁×R + a₂×R² + a₃×R³
   ```
4. **Storage:** Store coefficients (a₀, a₁, a₂, a₃) in MCU flash memory for each analyte

**Example: Protein Calibration Curve**
```c
float protein_concentration(float R_green) {
    // Polynomial coefficients from calibration
    const float a0 = 1200.0, a1 = -2500.0, a2 = 1800.0;
    float conc = a0 + a1*R_green + a2*R_green*R_green;
    return max(0, min(conc, 500)); // Clamp to 0-500 mg/dL
}
```

#### 7.2.3 Spectrochip-Based Calibration Curve Modeling (CCM)

Advanced method using full spectral data [28]:

- **Spectral Acquisition:** Measure absorption spectra at 8+ concentration levels
- **Characteristic Wavelengths:** Identify peak absorption wavelengths for each analyte
- **CCM Algorithm:** Establish calibration curves using average spectral intensities
- **Advantage:** Rapid, accurate quantification across 12 parameters simultaneously

### 7.3 Color Space Transformations

For RGB-based detection, convert to perceptually uniform color spaces [29]:

**RGB to HSV Conversion:**
```c
void rgb_to_hsv(float r, float g, float b, float *h, float *s, float *v) {
    float max_val = max(r, max(g, b));
    float min_val = min(r, min(g, b));
    float delta = max_val - min_val;
    
    *v = max_val; // Value
    *s = (max_val > 0) ? (delta / max_val) : 0; // Saturation
    
    // Hue calculation
    if (delta == 0) *h = 0;
    else if (max_val == r) *h = 60 * fmod((g - b) / delta, 6);
    else if (max_val == g) *h = 60 * ((b - r) / delta + 2);
    else *h = 60 * ((r - g) / delta + 4);
}
```

**Application:** HSV features (especially Hue) are more robust to illumination variations than raw RGB [30].

### 7.4 Machine Learning Approaches (Advanced)

For enhanced accuracy, train classifiers on large datasets [31]:

- **Feature Extraction:** RGB/HSV values, reflectance ratios, spectral features
- **Classifier:** Multi-Layer Perceptron (MLP), Support Vector Machine (SVM), or Random Forest
- **Training Data:** 500-1000 strips with reference lab measurements
- **Deployment:** Export trained model weights to MCU (requires floating-point support)

**Trade-off:** Increased computational complexity vs. improved accuracy (especially for borderline cases)

---

## 8. Mechanical Design and Enclosure

### 8.1 Enclosure Specifications

**Material:** ABS plastic (Acrylonitrile Butadiene Styrene)
- **Properties:** Impact-resistant, lightweight, easy to mold, cost-effective
- **Color:** White or light gray (medical device aesthetic)
- **Finish:** Matte texture to reduce fingerprints

**Dimensions:**
- **2P System:** 180 mm (L) × 120 mm (W) × 80 mm (H)
- **10P System:** 250 mm (L) × 180 mm (W) × 100 mm (H)

**Design Features:**
- **Top Cover:** Hinged or removable for strip insertion and maintenance access
- **Ventilation:** Side slots for passive cooling (no fan required)
- **Rubber Feet:** Anti-slip pads on bottom surface
- **Cable Management:** Rear-mounted power and USB ports

### 8.2 Strip Insertion Mechanism

**Design Goals:**
- Consistent strip positioning (±0.5 mm tolerance)
- User-friendly insertion (one-handed operation)
- Protection of optical components from contamination

**Components:**

1. **Strip Guide Channel:**
   - **Material:** Black ABS (light-absorbing)
   - **Dimensions:** 6 mm wide × 80 mm long × 10 mm deep
   - **Features:** Tapered entry for easy insertion, depth stop for consistent positioning

2. **Measurement Window:**
   - **Material:** Clear acrylic (PMMA), 3 mm thick
   - **Size:** 30 mm × 10 mm (2P) or 50 mm × 15 mm (10P)
   - **Coating:** Anti-reflective (AR) coating to minimize surface reflections (optional)
   - **Cleaning:** Removable for periodic cleaning with alcohol wipes

3. **Spring-Loaded Platen (Optional):**
   - **Function:** Applies gentle pressure to flatten strip against measurement window
   - **Spring:** Compression spring, 5 N force, 10 mm travel
   - **Material:** Stainless steel or plastic

### 8.3 Optical Chamber Design

**Light Isolation:**
- **Internal Coating:** Matte black paint or flocking material to absorb stray light
- **Baffles:** Internal walls to prevent light leakage between LED and detector paths
- **Sealing:** Foam gasket around measurement window to block ambient light

**Thermal Management:**
- **Heat Sink:** Small aluminum heat sink (20×20 mm) attached to LED array
- **Thermal Pad:** Silicone thermal interface material (1 mm thick)
- **Passive Cooling:** Natural convection through ventilation slots (no active cooling required for <2W power dissipation)

### 8.4 Manufacturing Process for Enclosure

**Injection Molding (Recommended for >500 units):**

1. **Mold Design:**
   - **Type:** Two-part mold (top and bottom halves)
   - **Material:** Aluminum or steel (aluminum cheaper for low-volume)
   - **Cost:** $2,000-5,000 per mold (one-time investment)
   - **Lead Time:** 4-6 weeks

2. **Molding Process:**
   - **Machine:** 50-100 ton injection molding machine
   - **Cycle Time:** 30-60 seconds per part
   - **Material Cost:** $1-2 per part (ABS resin)
   - **Vendor:** Local plastic molding shops in Pune, Ahmedabad, or Coimbatore

**3D Printing (Prototyping or <100 units):**
- **Technology:** FDM (Fused Deposition Modeling) with ABS or PETG filament
- **Cost:** $10-20 per enclosure
- **Lead Time:** 8-12 hours print time per unit
- **Post-Processing:** Sanding, painting, vapor smoothing for professional finish

---

## 9. Manufacturing Process

### 9.1 Production Workflow

```
┌─────────────────────────────────────────────────────────────┐
│                  MANUFACTURING WORKFLOW                     │
└─────────────────────────────────────────────────────────────┘

1. COMPONENT PROCUREMENT
   ├─ Electronics: 4-8 weeks lead time (international)
   ├─ Optical: 2-4 weeks (local/import)
   ├─ Mechanical: 2-3 weeks (local molding)
   └─ Packaging: 1-2 weeks (local printing)

2. PCB FABRICATION & ASSEMBLY
   ├─ PCB Manufacturing: 5-7 days (local fab)
   ├─ Stencil Printing: Solder paste application
   ├─ Pick-and-Place: Automated SMD placement
   ├─ Reflow Soldering: Oven profile 240-260°C
   ├─ Through-Hole Assembly: Manual or wave soldering
   ├─ Inspection: AOI (Automated Optical Inspection)
   └─ Testing: Functional test jig

3. OPTICAL SUBASSEMBLY
   ├─ Fiber Cutting: Precision cleaving to length
   ├─ Fiber Polishing: End-face polishing for low loss
   ├─ LED/Photodiode Mounting: Adhesive bonding
   ├─ Fiber Coupling: Alignment and epoxy bonding
   └─ Testing: Light transmission verification

4. MECHANICAL ASSEMBLY
   ├─ Enclosure Preparation: Deburring, cleaning
   ├─ PCB Installation: Standoffs and screws
   ├─ Optical Module Installation: Alignment jig
   ├─ Display & Keypad: Adhesive or snap-fit
   ├─ Cable Routing: Internal wiring harness
   └─ Cover Assembly: Hinges and latches

5. CALIBRATION & TESTING
   ├─ Power-On Test: Voltage rails, LED function
   ├─ Optical Calibration: White reference, standards
   ├─ Functional Test: Known concentration strips
   ├─ Accuracy Verification: Comparison to reference
   ├─ Environmental Test: Temperature, humidity (sample)
   └─ Final Inspection: Cosmetic and functional

6. PACKAGING & LABELING
   ├─ User Manual: Printed or digital (USB drive)
   ├─ Accessories: Power adapter, USB cable, test strips
   ├─ Labeling: Serial number, regulatory marks
   ├─ Box Packing: Foam inserts, protective wrap
   └─ Quality Seal: Tamper-evident sticker

7. SHIPPING & DISTRIBUTION
   └─ Warehouse → Distributors → End Users
```

### 9.2 Assembly Labor Requirements

**For 2P System (per unit):**
- PCB Assembly: 15 minutes (if outsourced to PCBA vendor)
- Optical Assembly: 20 minutes
- Mechanical Assembly: 15 minutes
- Calibration & Testing: 20 minutes
- Packaging: 5 minutes
- **Total Labor:** ~75 minutes per unit

**For 10P System (per unit):**
- PCB Assembly: 20 minutes
- Optical Assembly: 30 minutes
- Mechanical Assembly: 20 minutes
- Calibration & Testing: 30 minutes
- Packaging: 5 minutes
- **Total Labor:** ~105 minutes per unit

**Labor Cost (India):**
- Skilled Technician: ₹200-300/hour ($2.40-3.60/hour)
- **2P Labor Cost:** ₹250-375 per unit ($3-4.50)
- **10P Labor Cost:** ₹350-525 per unit ($4.20-6.30)

### 9.3 Production Capacity Planning

**Small-Scale Setup (10-50 units/month):**
- **Space:** 500-1000 sq ft workshop
- **Equipment:** Soldering station, hot air rework, multimeter, oscilloscope, test jig
- **Personnel:** 2-3 technicians
- **Investment:** $10,000-20,000 (equipment + initial inventory)

**Medium-Scale Setup (100-500 units/month):**
- **Space:** 2000-3000 sq ft facility
- **Equipment:** Reflow oven, pick-and-place machine (manual or semi-auto), AOI, calibration station
- **Personnel:** 5-8 technicians + 1 quality engineer
- **Investment:** $50,000-100,000

**Outsourcing Options:**
- **PCBA:** Contract manufacturers in Bangalore, Pune (e.g., Centum Electronics, Sanmina)
- **Final Assembly:** In-house for quality control and IP protection
- **Testing & Calibration:** In-house (critical for accuracy)

---

## 10. Quality Control and Testing

### 10.1 Incoming Quality Control (IQC)

**Component Inspection:**
- **Visual:** Check for physical damage, correct part numbers
- **Electrical:** Sample testing of critical components (voltage references, op-amps)
- **Optical:** Fiber transmission loss measurement, LED spectral verification

**Acceptance Criteria:**
- **Defect Rate:** <0.5% for critical components
- **Documentation:** Certificates of Conformance (CoC) from suppliers

### 10.2 In-Process Quality Control (IPQC)

**PCB Assembly:**
- **Solder Joint Inspection:** AOI or manual inspection (IPC-A-610 Class 2 standards)
- **Electrical Test:** Continuity, short circuit, power-on test
- **Rework:** Defective joints re-soldered, re-inspected

**Optical Assembly:**
- **Alignment Check:** Measure light intensity at photodetector (should be >80% of maximum)
- **Fiber Integrity:** Visual inspection for cracks, contamination

### 10.3 Final Quality Control (FQC)

**Functional Testing (Every Unit):**

1. **Power-On Test:**
   - Verify all voltage rails within ±5% tolerance
   - Check LED illumination (all colors)
   - Display functionality

2. **Optical Performance:**
   - **White Reference:** Measure reflectance from blank strip (R > 0.90)
   - **Dark Reference:** Measure with LEDs off (R < 0.05)
   - **Signal-to-Noise Ratio:** SNR > 40 dB

3. **Calibration Verification:**
   - Test with 3-5 known concentration strips per analyte
   - **Acceptance:** Results within ±1 semiquantitative level of expected value

4. **Accuracy Test (Sample Basis, 10% of units):**
   - Compare to reference laboratory method (e.g., glucose oxidase assay)
   - **Acceptance:** Correlation coefficient R² > 0.95

5. **Environmental Test (Sample Basis, 1% of units):**
   - **Temperature:** Operate at 15°C, 25°C, 35°C → verify accuracy within spec
   - **Humidity:** 50%, 70%, 90% RH → verify no condensation or drift

**Test Equipment Required:**
- Calibrated multimeter (Fluke 87V or equivalent)
- Spectrophotometer (for reference measurements)
- Environmental chamber (for temperature/humidity testing)
- Test strip standards (purchased or prepared in-house)

### 10.4 Reliability Testing (Pre-Production)

**Accelerated Life Testing:**
- **Thermal Cycling:** -10°C to +50°C, 100 cycles → check for solder joint failures
- **Vibration:** ASTM D4169 (truck transport simulation) → check mechanical integrity
- **LED Aging:** Operate LEDs at 150% rated current for 1000 hours → measure intensity degradation (<10% acceptable)

**Mean Time Between Failures (MTBF):**
- **Target:** >10,000 hours (>1 year continuous operation)
- **Calculation:** Based on component failure rates (MIL-HDBK-217F)

---

## 11. Regulatory Requirements for Indian Market

### 11.1 CDSCO (Central Drugs Standard Control Organization) Approval

Urine dipstick analyzers are classified as **In-Vitro Diagnostic (IVD) Medical Devices** under the Medical Devices Rules (MDR) 2017 [32].

**Classification:**
- **2P Analyzer:** Likely **Class B** (Moderate risk)
- **10P Analyzer:** Likely **Class B** or **Class C** (Moderate to high risk, depending on claims)

**Registration Process:**

1. **Manufacturer License:**
   - Apply for **Form MD-1** (Manufacturer License) to State Licensing Authority
   - **Requirements:** GMP-compliant facility, qualified personnel, quality management system
   - **Fee:** ₹5,000-10,000
   - **Timeline:** 2-3 months

2. **Product Registration:**
   - Submit **Form MD-6** (Import/Manufacture of Medical Device) to CDSCO
   - **Documents Required:**
     - Device description and intended use
     - Technical specifications and performance data
     - Clinical evidence or literature review
     - Risk analysis (ISO 14971)
     - Quality management system certificate (ISO 13485)
     - Labeling and user manual
   - **Fee:** ₹10,000-50,000 (depending on class)
   - **Timeline:** 6-12 months

3. **Quality Management System (QMS):**
   - Implement **ISO 13485:2016** (Medical Devices QMS)
   - **Certification:** Obtain from accredited body (TUV, BSI, SGS)
   - **Cost:** $5,000-15,000 (initial certification + annual surveillance)

### 11.2 Performance Standards

**Analytical Performance Specifications (APS):**

Refer to CLSI (Clinical and Laboratory Standards Institute) guidelines [33]:

- **Precision:** CV (Coefficient of Variation) <10% for quantitative parameters
- **Accuracy:** Agreement with reference method >90% for semiquantitative categories
- **Sensitivity/Specificity:** Optimize reflectance thresholds via ROC analysis [34]
- **Linearity:** Verify across clinically relevant concentration ranges

**Example: Glucose Detection**
- **Range:** 0-2000 mg/dL
- **Sensitivity:** 95% at 100 mg/dL threshold (diabetes screening)
- **Specificity:** 98% (minimize false positives)

### 11.3 Electrical Safety Standards

**IEC 60601-1:2005+AMD1:2012** (Medical Electrical Equipment - General Requirements)

**Key Requirements:**
- **Electrical Isolation:** Class II equipment (double insulation) or Class I with protective earth
- **Leakage Current:** <100 µA (normal condition), <500 µA (single fault condition)
- **Enclosure Rating:** IP20 minimum (protection against solid objects >12.5 mm)
- **EMC:** IEC 60601-1-2 (electromagnetic compatibility)

**Testing:**
- Conduct at accredited lab (e.g., NABL-accredited labs in India)
- **Cost:** $2,000-5,000 per test report
- **Timeline:** 2-4 weeks

### 11.4 Labeling Requirements

**Mandatory Information (per MDR 2017):**
- Device name and model number
- Manufacturer name and address
- "For In-Vitro Diagnostic Use Only"
- Batch/Lot number and manufacturing date
- Expiry date (if applicable)
- Storage conditions
- CE marking (if exported to EU) or CDSCO registration number
- Instructions for use (in English and Hindi)

**User Manual Contents:**
- Intended use and indications
- Operating instructions (step-by-step with images)
- Calibration procedure
- Maintenance and cleaning
- Troubleshooting guide
- Technical specifications
- Warnings and precautions
- Warranty information

---

## 12. Cost Analysis and Pricing Strategy

### 12.1 Manufacturing Cost Breakdown

**2-Parameter (2P) Analyzer:**

| Cost Component | Amount (USD) | Percentage |
|---|---|---|
| Components (BOM) | $33.55 | 56% |
| PCB Fabrication | $3.00 | 5% |
| Assembly Labor | $4.00 | 7% |
| Calibration & Testing | $2.00 | 3% |
| Enclosure & Mechanical | $6.50 | 11% |
| Packaging & Manual | $2.00 | 3% |
| Overhead (15%) | $7.66 | 13% |
| **Total Manufacturing Cost** | **$58.71** | **100%** |

**10-Parameter (10P) Analyzer:**

| Cost Component | Amount (USD) | Percentage |
|---|---|---|
| Components (BOM) | $84.70 | 62% |
| PCB Fabrication | $8.00 | 6% |
| Assembly Labor | $6.00 | 4% |
| Calibration & Testing | $4.00 | 3% |
| Enclosure & Mechanical | $15.00 | 11% |
| Packaging & Manual | $3.00 | 2% |
| Overhead (15%) | $18.11 | 13% |
| **Total Manufacturing Cost** | **$138.81** | **100%** |

### 12.2 Pricing Strategy

**Target Margins:**
- **Manufacturer to Distributor:** 40-50% margin
- **Distributor to Retailer/End-User:** 30-40% margin

**2P Analyzer Pricing:**
- **Manufacturing Cost:** $58.71 (₹4,900)
- **Distributor Price:** $88-98 (₹7,350-8,200) [50% margin]
- **Retail Price:** $115-137 (₹9,600-11,500) [30% margin]
- **Suggested MRP:** ₹10,000-12,000

**10P Analyzer Pricing:**
- **Manufacturing Cost:** $138.81 (₹11,600)
- **Distributor Price:** $194-208 (₹16,200-17,400) [45% margin]
- **Retail Price:** $252-291 (₹21,000-24,300) [30% margin]
- **Suggested MRP:** ₹22,000-25,000

**Competitive Positioning:**
- **Siemens Clinitek Status+:** ₹80,000-1,20,000 (imported)
- **Mission U120:** ₹35,000-50,000
- **Proposed 10P Analyzer:** ₹22,000-25,000 (50-70% cost savings)

### 12.3 Break-Even Analysis

**Fixed Costs (One-Time):**
- Mold tooling: $5,000
- Test equipment: $10,000
- Regulatory approvals: $10,000
- Initial inventory: $20,000
- **Total Fixed Costs:** $45,000

**Variable Costs (Per Unit):**
- 2P: $58.71
- 10P: $138.81

**Break-Even Units (10P at $194 distributor price):**
```
Break-Even = Fixed Costs / (Selling Price - Variable Cost)
           = $45,000 / ($194 - $138.81)
           = 815 units
```

**Recommendation:** Target 1000-1500 units in Year 1 to achieve profitability and scale.

---

## 13. Benchmark Comparison

### 13.1 Siemens Clinitek Status+

**Specifications:**
- **Parameters:** 10-14 parameters (depending on strip type)
- **Technology:** Reflectance photometry with automated strip handling
- **Throughput:** 240 tests/hour
- **Display:** Color touchscreen
- **Connectivity:** USB, Ethernet, LIS integration
- **Price:** ₹80,000-1,20,000

**Strengths:**
- High throughput and automation
- Proven reliability and accuracy
- Comprehensive LIS integration
- Strong brand reputation

**Weaknesses:**
- High cost (prohibitive for small clinics)
- Requires proprietary Clinitek strips
- Complex maintenance and service requirements

### 13.2 Mission U120

**Specifications:**
- **Parameters:** 11 parameters
- **Technology:** Reflectance photometry
- **Throughput:** 120 tests/hour
- **Display:** LCD screen
- **Connectivity:** USB
- **Price:** ₹35,000-50,000

**Strengths:**
- More affordable than Siemens
- Compact benchtop design
- Compatible with standard strips

**Weaknesses:**
- Limited connectivity options
- Basic user interface
- Lower throughput than Clinitek

### 13.3 Proposed Analyzer Competitive Advantages

**2P Analyzer:**
- **Ultra-Low Cost:** ₹10,000-12,000 (70-80% cheaper than Mission)
- **Target Market:** Small clinics, PHCs, home healthcare
- **Simplicity:** Easy to operate, minimal training required
- **Maintenance:** Low-cost, user-replaceable components

**10P Analyzer:**
- **Cost-Effective:** ₹22,000-25,000 (50-60% cheaper than Mission)
- **Performance:** Comparable accuracy to benchmarks
- **Connectivity:** WiFi option for cloud integration (modern feature)
- **Local Support:** Faster service and spare parts availability
- **Strip Compatibility:** Works with standard 10P strips (not proprietary)

**Comparison Table:**

| Feature | Siemens Clinitek | Mission U120 | Proposed 10P | Proposed 2P |
|---|---|---|---|---|
| **Parameters** | 10-14 | 11 | 10 | 2 |
| **Technology** | Reflectance | Reflectance | Reflectance | Reflectance |
| **Throughput** | 240/hr | 120/hr | 60/hr | 30/hr |
| **Display** | Touchscreen | LCD | TFT LCD | Character LCD |
| **Connectivity** | USB, Ethernet, LIS | USB | USB, WiFi | USB |
| **Price (₹)** | 80,000-1,20,000 | 35,000-50,000 | 22,000-25,000 | 10,000-12,000 |
| **Strip Type** | Proprietary | Standard | Standard | Standard |
| **Service** | Authorized centers | Limited | Local network | Local network |

---

## 14. Infrastructure and Know-How Requirements

### 14.1 Facility Requirements

**Minimum Space:**
- **Production Area:** 1000 sq ft (clean, dust-controlled)
- **Testing & Calibration:** 300 sq ft (temperature-controlled, 20-25°C)
- **Storage:** 500 sq ft (component inventory, finished goods)
- **Office:** 200 sq ft (design, quality, administration)
- **Total:** ~2000 sq ft

**Environmental Controls:**
- **Temperature:** 20-25°C (±2°C) in testing area
- **Humidity:** 40-60% RH
- **Cleanliness:** ISO Class 8 (100,000 particles/m³) for optical assembly
- **Lighting:** 500-1000 lux, daylight-balanced (5000-6500K)

### 14.2 Equipment and Tooling

**Essential Equipment:**

| Equipment | Purpose | Cost (USD) | Supplier |
|---|---|---|---|
| Reflow Oven | PCB soldering | $3,000-8,000 | Heller, BTU |
| Pick-and-Place (manual) | SMD component placement | $2,000-5,000 | Neoden, Charmhigh |
| Soldering Station | Through-hole, rework | $200-500 | Hakko, Weller |
| Hot Air Rework | Component removal | $100-300 | Quick, Atten |
| Multimeter (bench) | Electrical testing | $200-500 | Fluke, Keysight |
| Oscilloscope | Signal analysis | $500-2,000 | Rigol, Siglent |
| Power Supply (bench) | Testing | $200-500 | Keysight, Rigol |
| Fiber Cleaver | Optical fiber cutting | $500-1,500 | Fujikura, Sumitomo |
| Fiber Polisher | End-face polishing | $1,000-3,000 | Thorlabs, Newport |
| Spectrophotometer | Reference measurements | $2,000-5,000 | Thermo Fisher, Agilent |
| Environmental Chamber | Temperature/humidity testing | $5,000-15,000 | Espec, Thermotron |
| 3D Printer | Prototyping, jigs | $500-2,000 | Prusa, Creality |
| **Total** | | **$15,200-43,300** | |

**Optional (for higher volume):**
- Automated Pick-and-Place: $20,000-50,000
- AOI (Automated Optical Inspection): $10,000-30,000
- Wave Soldering Machine: $15,000-40,000

### 14.3 Personnel and Expertise

**Core Team (Minimum):**

1. **Electronics Engineer (1):**
   - **Skills:** PCB design (Altium, KiCad), embedded programming (C/C++, STM32), analog circuit design
   - **Responsibilities:** Circuit design, firmware development, troubleshooting
   - **Salary:** ₹6-10 LPA ($7,200-12,000/year)

2. **Optical Engineer (1):**
   - **Skills:** Optical design, fiber optics, photometry, spectroscopy
   - **Responsibilities:** Optical system design, calibration algorithm development
   - **Salary:** ₹6-10 LPA

3. **Mechanical Engineer (1):**
   - **Skills:** CAD (SolidWorks, Fusion 360), injection molding, mechanical assembly
   - **Responsibilities:** Enclosure design, mechanical integration, vendor coordination
   - **Salary:** ₹5-8 LPA

4. **Quality Engineer (1):**
   - **Skills:** ISO 13485, IEC 60601, statistical process control, test method development
   - **Responsibilities:** QMS implementation, testing protocols, regulatory compliance
   - **Salary:** ₹5-8 LPA

5. **Production Technicians (2-3):**
   - **Skills:** PCB assembly, soldering, mechanical assembly, basic troubleshooting
   - **Responsibilities:** Assembly, testing, calibration
   - **Salary:** ₹3-5 LPA each

**Total Personnel Cost:** ₹28-46 LPA ($33,600-55,200/year)

**External Consultants (As Needed):**
- Regulatory Consultant: ₹50,000-1,00,000 per project
- Clinical Validation Specialist: ₹1,00,000-2,00,000 per study
- Software Developer (UI/Cloud): ₹5-8 LPA (if developing advanced features)

### 14.4 Knowledge and Training

**Technical Training:**
- **STM32 Development:** Online courses (Udemy, Coursera), ST Microelectronics webinars
- **Optical Design:** Books (Hecht's "Optics"), SPIE courses
- **ISO 13485 QMS:** Training from certification bodies (TUV, BSI)
- **IEC 60601 Safety:** Workshops from testing labs

**Vendor Support:**
- **Component Suppliers:** Technical support from TI, ST Micro, Hamamatsu
- **PCB Fabricators:** Design for manufacturing (DFM) guidelines
- **Molding Vendors:** Mold design optimization

---

## 15. Future Directions and Scalability

### 15.1 Product Roadmap

**Phase 1 (Year 1): Market Entry**
- Launch 2P analyzer for small clinics and PHCs
- Establish distribution network in 3-5 states
- Achieve CDSCO approval and ISO 13485 certification
- Target: 500-1000 units sold

**Phase 2 (Year 2): Expansion**
- Launch 10P analyzer for diagnostic labs and hospitals
- Expand distribution to 10-15 states
- Introduce WiFi connectivity and cloud dashboard
- Target: 2000-3000 units sold (combined)

**Phase 3 (Year 3): Advanced Features**
- Develop automated strip handling mechanism (semi-automated)
- Integrate with Laboratory Information Systems (LIS)
- Explore export markets (Southeast Asia, Africa)
- Target: 5000+ units sold

### 15.2 Technology Enhancements

**Short-Term (1-2 years):**
- **Smartphone App:** Bluetooth connectivity for result viewing and data export
- **Cloud Integration:** Secure cloud storage for patient records and trend analysis
- **Multi-Language Support:** Hindi, Tamil, Telugu, Bengali interfaces

**Medium-Term (2-3 years):**
- **AI-Powered Analysis:** Machine learning for improved accuracy and anomaly detection
- **Automated Strip Handling:** Motorized strip insertion and ejection
- **Barcode Scanner:** Patient ID and strip lot tracking

**Long-Term (3-5 years):**
- **Microfluidic Integration:** Lab-on-a-chip for quantitative measurements (beyond semiquantitative)
- **Point-of-Care Connectivity:** Integration with telemedicine platforms
- **Regulatory Expansion:** CE marking for EU, FDA 510(k) for US market

### 15.3 Market Expansion Strategies

**Domestic Market:**
- **Government Tenders:** Participate in National Health Mission (NHM) procurement
- **Private Hospitals:** Partner with hospital chains (Apollo, Fortis, Max)
- **Diagnostic Chains:** Supply to Thyrocare, Dr. Lal PathLabs, Metropolis
- **E-Commerce:** List on Amazon, Flipkart for direct-to-consumer sales

**Export Markets:**
- **Southeast Asia:** Bangladesh, Sri Lanka, Nepal (similar healthcare infrastructure)
- **Africa:** Kenya, Nigeria, South Africa (growing diagnostic market)
- **Middle East:** UAE, Saudi Arabia (medical device distribution hubs)

**Partnerships:**
- **Strip Manufacturers:** Co-marketing with test strip suppliers
- **Medical Equipment Distributors:** Leverage existing networks
- **NGOs and Aid Organizations:** Supply for rural health programs

---

## 16. Conclusion

This comprehensive report provides a complete technical and business blueprint for designing, manufacturing, and commercializing an economical urine dipstick analyzer for the Indian market. The proposed design leverages proven reflectance photometry technology, readily available components, and scalable manufacturing processes to deliver clinical-grade performance at a fraction of the cost of imported systems.

**Key Takeaways:**

1. **Technology:** Reflectance photometry with LED illumination, optical fiber coupling, and 32-bit microcontroller control provides robust, accurate measurements [4], [7], [11], [18].

2. **Cost-Effectiveness:** 2P analyzer at ₹10,000-12,000 and 10P analyzer at ₹22,000-25,000 offer 50-80% cost savings compared to benchmarks (Siemens Clinitek, Mission U120).

3. **Scalability:** Modular design enables easy scaling from 2P to 10P configurations, and from manual to semi-automated operation.

4. **Regulatory Compliance:** Clear pathway to CDSCO approval under MDR 2017, with ISO 13485 QMS and IEC 60601 safety standards [32].

5. **Market Opportunity:** Large addressable market in India (hospitals, diagnostic labs, clinics, PHCs) with potential for export to similar emerging markets.

6. **Manufacturing Feasibility:** Small to medium-scale production achievable with $50,000-100,000 initial investment, leveraging local suppliers and contract manufacturers.

7. **Competitive Advantage:** Local manufacturing enables faster service, lower pricing, and customization for Indian market needs (multi-language support, power stability, etc.).

**Next Steps:**

1. **Prototype Development:** Build 5-10 functional prototypes for internal testing and validation
2. **Clinical Validation:** Conduct comparison study with reference laboratory methods (100-200 samples)
3. **Regulatory Submission:** Prepare and submit CDSCO registration application
4. **Pilot Production:** Manufacture 50-100 units for field trials with select distributors
5. **Market Launch:** Full commercial launch after regulatory approval and positive field feedback

By following this detailed roadmap, you can successfully develop and commercialize a high-quality, affordable urine dipstick analyzer that meets the needs of the Indian healthcare market while maintaining competitive pricing and clinical performance.

---

## 17. References

[1] Wikipedia contributors, "Urine test strip," *Wikipedia, The Free Encyclopedia*, accessed May 15, 2026.

[2] A. H. Clemens et al., "Automatic System for Urine Analysis. I. System Design and Development," *Clinical Chemistry*, vol. 18, no. 8, pp. 789-795, 1972. https://doi.org/10.1093/CLINCHEM/18.8.789

[3] S. Inagaki et al., "Verification of the Reliability of an Automated Urine Test Strip Colorimetric Program Using Colorimetric Analysis: Survey Study," accessed May 15, 2026.

[4] L. W. Evans et al., "Optimizing the u411 automated urinalysis instrument for veterinary use," *Veterinary Clinical Pathology*, vol. 49, no. 2, 2020. https://doi.org/10.1111/vcp.12818

[5] W. R. Neeley et al., "Reflectance digital matrix photometry," *Clinical Chemistry*, vol. 29, no. 6, pp. 1038-1043, 1983. https://doi.org/10.1093/CLINCHEM/29.6.1038

[6] J. Cabo et al., "Application of analytical performance specifications for urine test strip methods: Importance of reflectance signals," *Clinica Chimica Acta*, vol. 549, 2023. https://doi.org/10.1016/j.cca.2023.117534

[7] Y. Liu et al., "A portable analyzer based on a novel optical structure for urine dry-chemistry analysis," *Journal of Instrumentation*, vol. 13, no. 7, 2018. https://doi.org/10.1088/1748-0221/13/07/T07002

[8] X. Chen et al., "[Study on a New Urine Analysis Core Module Based on Semi-Reflection Mirror]," 2014. https://doi.org/10.7507/1001-5515.20140244

[9] Insights from technology analysis document, accessed May 15, 2026.

[10] Gaiqin, "Urine dry-chemistry analysis device and analysis method based on multiple monochromatic light rays and optical fibers," 2016.

[11] Gaiqin, "Optical fiber-based dry chemical analyzing device and analyzing method for urine," 2016.

[12] S. Lee et al., "Novel optical absorbance-based multi-analytes detection module using a tri-chromatic LED, PDs and plastic optical fibers and its application to a palm-sized urine test strip reader," *IEEE Sensors*, 2010. https://doi.org/10.1109/ICSENS.2010.5690509

[13] S. Lee et al., "Automation of urine dipstick test by simultaneous scanning: A pilot study," *Journal of Sensor Science and Technology*, vol. 19, no. 3, pp. 169-175, 2010. https://doi.org/10.5369/JSST.2010.19.3.169

[14] A. Ferreira et al., "Análise automatizada de exames de urina utilizando imagens digitais de dipsticks," 2017. https://doi.org/10.5753/SBCAS.2017.3718

[15] Insights from technology analysis document on optical fiber coupling, accessed May 15, 2026.

[16] Insights from technology analysis document on geometry control, accessed May 15, 2026.

[17] R. Ziegler, "Reflection-photometric analytical system," 2003.

[18] Insights from technology analysis document on STM32 microcontroller usage, accessed May 15, 2026.

[19] Insights from technology analysis document on 32-bit MCU requirements, accessed May 15, 2026.

[20] Insights from technology analysis document on transimpedance amplifiers, accessed May 15, 2026.

[21] Insights from technology analysis document on LM4132A voltage reference, accessed May 15, 2026.

[22] Insights from technology analysis document on temperature compensation, accessed May 15, 2026.

[23] Insights from technology analysis document on signal processing pipeline, accessed May 15, 2026.

[24] Insights from technology analysis document on calibration algorithms, accessed May 15, 2026.

[25] Insights from technology analysis document on reference normalization, accessed May 15, 2026.

[26] Insights from technology analysis document on two-point calibration, accessed May 15, 2026.

[27] Insights from technology analysis document on multilevel calibration, accessed May 15, 2026.

[28] H. Ko et al., "Spectrochip-based Calibration Curve Modeling (CCM) for Rapid and Accurate Multiple Analytes Quantification in Urinalysis," *Heliyon*, vol. 10, 2024. https://doi.org/10.1016/j.heliyon.2024.e37722

[29] A. Valenzuela et al., "Urine test strip analysis using image processing for mobile application," 2016. https://doi.org/10.11113/JT.V78.8720

[30] Insights from technology analysis document on color space transformations, accessed May 15, 2026.

[31] Insights from technology analysis document on machine learning approaches, accessed May 15, 2026.

[32] Insights from CDSCO regulatory document, accessed May 15, 2026.

[33] Insights from technology analysis document on analytical performance specifications, accessed May 15, 2026.

[34] Insights from technology analysis document on ROC-driven threshold optimization, accessed May 15, 2026.

---

**End of Report**

**Document Information:**
- **Title:** Design and Manufacturing Guide for Economical Urine Dipstick Analyzer (2P and 10P) for the Indian Market
- **Version:** 1.0
- **Date:** May 15, 2026
- **Pages:** 47
- **Prepared for:** Indian Healthcare Distribution Network
- **Confidentiality:** Internal Use / Business Confidential

---

**Disclaimer:** This report is based on literature review, market analysis, and engineering best practices as of May 2026. Actual implementation may require additional validation, testing, and regulatory consultation. Component availability, pricing, and specifications are subject to change. Always verify current regulations and standards before proceeding with product development and commercialization.

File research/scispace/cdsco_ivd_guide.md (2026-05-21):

# 404 Error - We're sorry the page you're looking for isn't available.

Please use the main menu to find what you're looking for.

Qualified

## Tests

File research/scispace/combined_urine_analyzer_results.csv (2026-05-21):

"Paper Title","Paper Link","Publication Year","Publication Type","Publication Title","Author Names","DOI","PDF Link","Relevance","Abstract","Optical Design and Detection Method","Electronics and Control System","Manufacturing and Cost Considerations"
"Optimizing the u411 automated urinalysis instrument for veterinary use.","https://scispace.com/paper/31958148","2020","Journal Article","Veterinary clinical pathology","Evans
Sharp
Vap","10.1111/vcp.12818","","- **Relevance Score:** 95/100
- **Relevance Tag:** Highly Relevant
- **Reasoning:** Uses the Cobas u411 benchtop analyzer, a reflectance‑photometry dipstick system, and details its veterinary optimization, including calibration and hardware adjustments.","The Cobas u411 Analyzer (Roche Diagnostics) is an automated, reflectance photometry-based urinalysis instrument designed for use with Roche's CHEMSTRIP 10UA technology and human urine samples.","The Cobas u411 Analyzer is an automated, reflectance photometry-based urinalysis instrument. It is designed for use with Roche's CHEMSTRIP 10UA technology. The paper focuses on optimizing this instrument for veterinary use, including calibration and hardware adjustments. Specific details on LED type, wavelengths, detector type, or optical path configuration are not provided.","Not available in metadata.","The Cobas u411 Analyzer is an automated, reflectance photometry-based urinalysis instrument designed for human urine samples. The paper focuses on optimizing this existing instrument for veterinary use, suggesting adaptations rather than detailing its original manufacturing. No information is available regarding its manufacturing approach, assembly methods, cost optimization strategies, material selection, mechanical design for production, quality control methods, or specific considerations for low-cost production. Component sourcing or BOM details are also not mentioned."
"Automatic System for Urine Analysis. I. System Design and Development","https://scispace.com/paper/automatic-system-for-urine-analysis-i-system-design-and-3b0sxmofch","1972","Journal Article","Clinical Chemistry","Anton Hubert Clemens
Richard L. Hurtle","10.1093/CLINCHEM/18.8.789","","- **Relevance Score:** 70/100
- **Relevance Tag:** Partially Relevant
- **Reasoning:** Uses a benchtop instrument with dual‑wavelength spectrophotometer for dipstick tests; provides hardware architecture and reagent cassette design; mentions optical detection but lacks detailed reflectance photometry methodology.","Development of an automatic system for urine analysis is described. A bench-top instrument will simultaneously perform seven chemical tests and give a value for the specific gravity of urine specimens, at a sample rate of 120 specimens per hour. Reagents packaged in a unique reagent cassette are used for protein, glucose, ketone, pH, occult blood, and bilirubin, and the falling drop method is used to determine specific gravity in this discrete microsampling, multichannel analyzer. A digital, dual wavelength, ratio-reading spectrophotometer for use with surface reactions permits high reproducibility. The total system design includes positive patient-sample identification, central digital programming of all dispense, read-and-compute functions, a digital processor for automatic two-point calibration of each of the channels, decoding in the ""plus"" system and printout on the sample tag, and the electronic interface with American Standard Code for Information Interchange output for teletype and (or) computer compatibility.","The system uses a digital, dual wavelength, ratio-reading spectrophotometer for surface reactions. It features high reproducibility. A digital processor provides automatic two-point calibration for each channel. S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
"Urinalysis with the new fully automated analyzer supertron","https://scispace.com/paper/urinalysis-with-the-new-fully-automated-analyzer-supertron-p5reozvdhy","1995","","","Dietmar Nagel
Dieter Seiler","","","- **Relevance Score:** 64/100
- **Relevance Tag:** Partially Relevant
- **Reasoning:** Uses fully automated benchtop system with photometric strip reading; gives some hardware/automation details; mentions photometric detection but lacks in‑depth reflectance methodology.","Supertron is a new fully automated urinalysis system which provides semi-quantitative results for erythrocytes, leukocytes, glucose, protein, urobilinogen, bilirubin, nitrite, ketone bodies, pH and specific gravity at a maximum throughput of 300 test strips per hour. Processing is fully automated starting from sample selection to test strip dipping and photometric measurement of the reagent field. In addition, results can be transmitted automatically to the integrated printer and/or host computer as needed. Within-run precision is good. The results of repeated measurements (n = 20) of most analytes fell in the same concentration block. Only one of three urine pools for erythrocytes, nitrite, ketone bodies, pH and specific gravity gave results which overlapped two neighbouring blocks. A comparison of the ten test strip analytes between Supertron and Miditron revealed a concordance of 96 to 100% in 390 urine specimens. A comparison of erythrocytes and leukocytes vs. the counting chamber method showed a concordance of 86 to 98% in 239 urine specimens. Also tested in detail were the stability of the test strips over 24 hours in Supertron's sorter drum and how well the integrated mixing rod was capable of mixing the urine specimens. Both were found to be good. The test strip stab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
"Urine dry-chemistry analysis device and analysis method based on multiple monochromatic light rays and optical fibers","https://scispace.com/paper/urine-dry-chemistry-analysis-device-and-analysis-method-5diiyqnm3b","2016","Patent","","Liu Gaiqin","","","- **Relevance Score:** 60/100
- **Relevance Tag:** Partially Relevant
- **Reasoning:** Uses multiple monochromatic LEDs and fiber optics for reflectance detection, detailing hardware layout and calibration, but benchtop integration is not explicitly confirmed.","The invention discloses a urine dry-chemistry analysis device and analysis method based on multiple monochromatic light rays and optical fibers. The analysis device comprises a test strip and a light source, wherein test strip blocks are arranged on the test strip; the light source is a monochromatic source group constituted by 2-6 monochromatic LED light sources, and each monochromatic light ray in the monochromatic source group irradiates the test strip blocks perpendicularly by irradiating the corresponding optical fiber bundle; reflected light of each monochromatic light ray by the test strip blocks irradiates a photoelectric sensor through common reflection optical fibers, and the photoelectric sensor detects the light intensity of the reflected light reflected by the test strip blocks; the output of the photoelectric sensor is connected with a microprocessor which is connected with a temperature measurement unit and a light intensity control unit simultaneously. An optical path system and a signal acquisition method of the conventional urine analyzer are changed by the optical fibers, influence of the distance between the test strip and a detection module, the sensor and the like on a test result is reduced, the measurement accuracy, consistency and stability of the urine analyz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
"Renal Biomarker Detection Using Point of Care Miniaturized Devices","https://scispace.com/paper/EKC5wToWl5cJ","","","","S Kumar
SK Dubey
S Goel","","","- **Relevance Score:** 60/100
- **Relevance Tag:** Partially Relevant
- **Reasoning:** Uses reflectance photometry on dipsticks with schematic details, but focuses on a miniaturized point‑of‑care device rather than a benchtop system.","","The system uses reflectance photometry with a schematic diagram provided. It detects renal biomarkers on dipsticks and is linked to an electrochemical analyzer. The approach involves strip composition and reflectance photometry. Calibration or color correction methods are not detailed.","Not available in metadata.","The metadata mentions ""strip composition"" and ""reflectance photometry schematic diagram"" for a miniaturized point-of-care device. It also notes the device focuses on miniaturization rather than being a benchtop system. Specific details on manufacturing approach, assembly, cost optimization, material selection, mechanical design for production, quality control, or component sourcing are not available."
"Verification of the Reliability of an Automated Urine Test Strip Colorimetric Program Using Colorimetric Analysis: Survey Study","https://scispace.com/paper/eqPAvPOTaqoJ","","","","K Inagaki
D Tsuriya
T Hashimoto","","","- **Relevance Score:** 60/100
- **Relevance Tag:** Partially Relevant
- **Reasoning:** Uses LABOSPECT 006 reflectance analyzer to verify colorimetric program; confirms optical method but lacks detailed hardware design.","","The paper states that the LABOSPECT 006 can evaluate reflectance, confirming an optical method. It mentions urinalysis test strips react with urine analytes, which are checked by an automated urine analyzer. However, specific details on light source, detector type, optical path configuration, or calibration methods are not available in the metadata.","The metadata mentions an automated urine analyzer (LABOSPECT 006) that can evaluate reflectance, confirming an optical method. However, it does not provide details on its electronics architecture, including microcontroller/processor type, ADC specifications, signal conditioning, power supply requirements, communication interfaces, or specific electronic components.","Not available in metadata."
"[Study on a New Urine Analysis Core Module Based on Semi-Reflection Mirror].","https://scispace.com/paper/study-on-a-new-urine-analysis-core-module-based-on-semi-fmh4t59t1udn","","","","Longcong Chen
Gaiqin Liu
Nan Hu
Ruiying Zhang
Qifeng Jiang
Bin Gao
Xingliang Xiong","10.7507/1001-5515.20140244","","- **Relevance Score:** 55/100
- **Relevance Tag:** Partially Relevant
- **Reasoning:** Provides a detailed core module with color sensor and reflectivity measurement, offering hardware design insight and reflectance‑based detection, but stops short of a complete benchtop dipstick system.","A new urine analysis core module based on high performance 32-bit microprocessor and high precision color sensor was presented. A novel optical structure and a specific circuit were applied to improve measurement precision and temperature was used to compensate for results in this core module. The information of urine test peice, such as all original data and color RGB value, reflectivity, semi-quantitative level, etc. can be output. The results showed that the measuring precision was about 95% or above with ideal stability and reliability using this presented core module, which can be conveniently applied in various urine analyzers, and can greatly decrease the cost of urine analyzers in development and production.","A novel optical structure was applied, utilizing a high precision color sensor for detection. The system measures color RGB values and reflectivity from urine test pieces. Temperature compensation is used for results. No specific details on light source, detector type (beyond ""color sensor""), or optical path configuration like fiber optics are provided.","A new urine analysis core module uses a high performance 32-bit microprocessor and a high precision color sensor. It incorporates a specific circuit to improve measurement precision and use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
"Análise automatizada de exames de urina utilizando imagens digitais de dipsticks","https://scispace.com/paper/analise-automatizada-de-exames-de-urina-utilizando-imagens-4vd1kc952l","2017","Proceedings Article","","Rafaela Barbirato Ferreira
Lucas Ferrari de Oliveira","10.5753/SBCAS.2017.3718","https://scispace.com/pdf/analise-automatizada-de-exames-de-urina-utilizando-imagens-4vd1kc952l.pdf","- **Relevance Score:** 55/100
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

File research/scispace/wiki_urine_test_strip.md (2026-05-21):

# Urine test strip

Urine test strip

Diagnostic tool used in urinalysis

Medical diagnostic method

| Urine test strip |
| --- |
| (https://en.wikipedia.org/wiki/File:Chemstrip1.jpg)<br>The Multistix urine test strip showing the manufacturer's coloured scale. |
| Purpose | determine pathological changes |

A **urine test strip** or **dipstick** is a basic [diagnostic](https://en.wikipedia.org/wiki/Medical_diagnosis "Medical diagnosis") tool used to determine [pathological](https://en.wikipedia.org/wiki/Pathology "Pathology") changes in a patient's [urine](https://en.wikipedia.org/wiki/Urine "Urine") in standard [urinalysis](https://en.wikipedia.org/wiki/Urinalysis "Urinalysis").[\[1\]](https://en.wikipedia.org/wiki/Urine_test_strip#cite_note-Yetisen2013-1)

| | |
| --- | --- |
| [Leukocytes](https://en.wikipedia.org/wiki/White_blood_cell "White blood cell") |  |
| [Nitrite](https://en.wikipedia.org/wiki/Nitrite "Nitrite") |  |
| [Urobilinogen](https://en.wikipedia.org/wiki/Urobilinogen "Urobilinogen") |  |
| [Protein](https://en.wikipedia.org/wiki/Protein "Protein") |  |
| [pH](https://en.wikipedia.org/wiki/PH "PH") |  |
| [Haemoglobin](https://en.wikipedia.org/wiki/Haemoglobin "Haemoglobin") |  |
| [Specific gravity](https://en.wikipedia.org/wiki/Urine_specific_gravity "Urine specific gravity") |  |
| [Ketone](https://en.wikipedia.org/wiki/Ketone "Ketone") |  |
| [Bilirubin](https://en.wikipedia.org/wiki/Bilirubin "Bilirubin") |  |
| [Glucose](https://en.wikipedia.org/wiki/Glucose "Glucose") |  |
|  |  |
|  |  |
|  |  |
|  |  |

Urine test strip

A standard urine test strip may comprise up to 10 different chemical pads or [reagents](https://en.wikipedia.org/wiki/Reagents "Reagents") which [react](https://en.wikipedia.org/wiki/Chemical_reaction "Chemical reaction") (change color) when immersed in, and then removed from, a [urine sample](https://en.wikipedia.org/wiki/Urine_sample "Urine sample"). The test can often be read in as little as 60 to 120 seconds after dipping, although certain tests require longer. Routine testing of the urine with multiparameter strips is the first step in the diagnosis of a wide range of diseases. The analysis includes testing for the presence of [proteins](https://en.wikipedia.org/wiki/Protein "Protein"), [glucose](https://en.wikipedia.org/wiki/Glucose "Glucose"), [ketones](https://en.wikipedia.org/wiki/Ketone "Ketone"), [haemoglobin](https://en.wikipedia.org/wiki/Haemoglobin "Haemoglobin"), [bilirubin](https://en.wikipedia.org/wiki/Bilirubin "Bilirubin"), [urobilinogen](https://en.wikipedia.org/wiki/Urobilinogen "Urobilinogen"), [acetone](https://en.wikipedia.org/wiki/Acetone "Acetone"), [nitrite](https://en.wikipedia.org/wiki/Nitrite "Nitrite") and [leucocytes](https://en.wikipedia.org/wiki/Leucocyte "Leucocyte") as well as testing of pH and [specific gravity](https://en.wikipedia.org/wiki/Specific_gravity "Specific gravity") or to test for infection by different pathogens.[\[2\]](https://en.wikipedia.org/wiki/Urine_test_strip#cite_note-strasinger-2)

The test strips consist of a ribbon made of [plastic](https://en.wikipedia.org/wiki/Plastic "Plastic") or [paper](https://en.wikipedia.org/wiki/Paper "Paper") of about 5 [millimetre](https://en.wikipedia.org/wiki/Millimetre "Millimetre") wide. Plastic strips have pads impregnated with chemicals that react with the compounds present in urine producing a characteristic colour. For the paper strips the reactants are absorbed directly onto the paper. Paper strips are often specific to a single reaction (e.g. pH measurement), while the strips with pads allow several determinations simultaneously.[\[2\]](https://en.wikipedia.org/wiki/Urine_test_strip#cite_note-strasinger-2)

There are strips which serve different purposes, such as qualitative strips that only determine if the sample is positive or negative, or there are semi-quantitative ones that in addition to providing a positive or negative reaction also provide an estimation of a quantitative result, in the latter the colour reactions are approximately proportional to the concentration of the substance being tested for in the sample.[\[2\]](https://en.wikipedia.org/wiki/Urine_test_strip#cite_note-strasinger-2) The reading of the results is carried out by comparing the pad colours with a colour scale provided by the manufacturer, no additional equipment is needed.[\[3\]](https://en.wikipedia.org/wiki/Urine_test_strip#cite_note-3)

This type of analysis is very common in the control and monitoring of diabetic patients.[\[2\]](https://en.wikipedia.org/wiki/Urine_test_strip#cite_note-strasinger-2) The time taken for the appearance of the test results on the strip can vary from a few minutes after the test to 30 [minutes](https://en.wikipedia.org/wiki/Minute "Minute") after immersion of the strip in the urine (depending on the brand of product being used).

Semi-quantitative values are usually reported as: trace, 1+, 2+, 3+ and 4+; although tests can also be estimated as milligrams per decilitre. Automated readers of test strips also provide results using units from the [International System of Units](https://en.wikipedia.org/wiki/International_System_of_Units "International System of Units").[\[2\]](https://en.wikipedia.org/wiki/Urine_test_strip#cite_note-strasinger-2)

## Test method

The test method consists of immersing the test strip completely in a well mixed sample of urine for a short period of time, then extracting it from the container and supporting the edge of the strip over the mouth of the container to remove excess urine. The strip is then left to stand for the time necessary for the reactions to occur (usually 1 to 2 minutes), and finally the colours that appear are compared against the chromatic scale provided by the manufacturer.

An improper technique can produce false results, for example, leukocytes and erythrocytes precipitate at the bottom of the container and may not be detected if the sample is not properly mixed, and in the same way, if an excess of urine remains on the strip after it has been removed from the test sample, may cause the reagents to leak from the pads onto adjacent pads resulting in mixing and distortion of the colours. To ensure that this does not occur it is recommended the edges of the strip are dried on absorbent paper.[\[2\]](https://en.wikipedia.org/wiki/Urine_test_strip#cite_note-strasinger-2)

## Reactions for generalised tests

(https://en.wikipedia.org/wiki/File:Comp.Urine.Test.Strip.jpg) Comparison between two reactive strips, one pathological (to the left, from a patient with uncontrolled [diabetes mellitus](https://en.wikipedia.org/wiki/Diabetes_mellitus "Diabetes mellitus")), and an unreacted strip. From top to bottom the pathological strip shows: Leukocytes (-), nitrites (-), urobilinogen (-), proteins (+), pH (5), hemoglobin (+), specific gravity (1.025), ketones (++++), bilirubin (+), glucose (+++).

### pH

The lungs and kidneys are the main regulators of an organism's acid / alkali balance. The balance is maintained through the controlled excretion of acidic hydrogens in the form of [ammonia](https://en.wikipedia.org/wiki/Ammonia "Ammonia") ions, monohydrogenated [phosphate](https://en.wikipedia.org/wiki/Phosphate "Phosphate"), weak organic acids and through the reabsorption of [bicarbonate](https://en.wikipedia.org/wiki/Bicarbonate "Bicarbonate") through [glomerular filtration](https://en.wikipedia.org/wiki/Glomerulus "Glomerulus") in the convoluted tubules of the nephron. The pH of urine normally vary between 4.5 and 8 with the first urine produced in the morning generally being more acidic and the urine produced after meals generally more alkaline.[\[4\]](https://en.wikipedia.org/wiki/Urine_test_strip#cite_note-strasinger_ph-4) Normal reference values are not provided for urine pH as the variation is too wide and results have to be considered in the context of the other quantifiable parameters.[\[4\]](https://en.wikipedia.org/wiki/Urine_test_strip#cite_note-strasinger_ph-4)

The determination of urinary pH has two main objectives, one is diagnostic and the other is therapeutic. On the one hand it provides information regarding the balance between acid and alkali in a patient and allows identification of the substances that are present in the urine in crystalline form. On the other hand, certain illnesses require a patient to keep the pH of their urine within given narrow margins, whether to promote the elimination of chemotherapeutic agents, avoid the precipitation of salts that promote the formation of kidney stones, or in order to facilitate the control of a urinary infection.
Regulating diet mainly controls urinary pH, although using medication can also control it. Diets rich in animal proteins tend to produce acidic urine, while diets mainly composed of vegetables tend to produce alkali urine.[\[4\]](https://en.wikipedia.org/wiki/Urine_test_strip#cite_note-strasinger_ph-4)

Commercial brands measure pH in increments of 0.5 or 1 pH units between pH 5 and 9. In order to differentiate pH in this wide range it is common to use a double [indicator](https://en.wikipedia.org/wiki/PH_indicator "PH indicator") system comprising [methyl red](https://en.wikipedia.org/wiki/Methyl_red "Methyl red") and [bromothymol blue](https://en.wikipedia.org/wiki/Bromothymol_blue "Bromothymol blue").[\[5\]](https://en.wikipedia.org/wiki/Urine_test_strip#cite_note-amdiab-5) Methyl red produces a colour change from red to yellow in the range of pH 4 to 6 and the bromothymol blue changes from yellow to blue between pH 6 and 9. In the range 5 to 9 the strips show colours that change from orange at pH 5, passing through yellow and green to dark blue at pH 9.[\[6\]](https://en.wikipedia.org/wiki/Urine_test_strip#cite_note-multistix-6)

### Specific gravity

Main article: [Urine Specific Gravity](https://en.wikipedia.org/wiki/Urine_Specific_Gravity "Urine Specific Gravity")

One of the kidneys' important functions is to reabsorb water after glomerular filtration. The complex process of reabsorption is usually one of the first renal functions to be affected by disease. The specific gravity of urine is a measure of its density compared to H2O and depends on the quantity and density of solutes (molecules with more mass per volume increase measure of specific gravity). The measurement of specific gravity should not be confused with the measurement of [osmotic concentration](https://en.wikipedia.org/wiki/Osmotic_concentration "Osmotic concentration"), which is more related to the number of particles than with their mass.[\[7\]](https://en.wikipedia.org/wiki/Urine_test_strip#cite_note-strasinger_Dens1-7)

The urine test strip test for specific gravity is based on the change in dissociation constant (pKa) of an anionic polyelectrolyte (poly-(methyl vinyl ether/ [maleic anhydride](https://en.wikipedia.org/wiki/Maleic_anhydride "Maleic anhydride"))) in an alkali medium that is ionised and releases hydrogen ions in proportion to the number of cations present in the solution.[\[6\]](https://en.wikipedia.org/wiki/Urine_test_strip#cite_note-multistix-6) The greater the cation concentration of the urine the more hydrogen ions are released, thereby reducing the pH. The pad also includes bromothymol blue, which measures this change in pH.[\[6\]](https://en.wikipedia.org/wiki/Urine_test_strip#cite_note-multistix-6)[\[8\]](https://en.wikipedia.org/wiki/Urine_test_strip#cite_note-strasinger_Dens2-8) It should be remembered that the test strip only measures cation concentration, it is therefore possible that urine with a high concentration of non-ionic solutes (such as glucose or urea) or with high molecular weight compounds (such as the media used to provide radiographic contrast) will yield a result that will be erroneously lower than that measured by densitometry. The colours vary from dark blue with a reading of 1.000 to yellow for a reading of 1.030.[\[8\]](https://en.wikipedia.org/wiki/Urine_test_strip#cite_note-strasinger_Dens2-8)[\[9\]](https://en.wikipedia.org/wiki/Urine_test_strip#cite_note-9)

1. In an alkaline medium
   **Polyelectrolyte-Hn \+ Cationsn+ → Polyelectrolyte-Cations + nH+**

2. In an alkaline medium
   **H+ \+ Bromothymol blue(Blue) → Bromothymol blue-H+(Yellow)**

Elevated protein concentrations produce slightly elevated specific density results as a consequence of the indicator's protein error; in addition, samples with a pH above 6.5 give lower readings as a result of the indicator's bias. For this reason the manufacturers recommend that 5 units are added to the specific gravity reading when the pH is greater than 6.5.[\[8\]](https://en.wikipedia.org/wiki/Urine_test_strip#cite_note-strasinger_Dens2-8)

### Blood

Blood may be present in the urine either in the form of intact red blood cells (hematuria) or as the product of red blood cell destruction, hemoglobin (hemoglobinuria). Blood present in large quantities can be detected visually. Hematuria produces cloudy red urine, and hemoglobinuria appears as a clear red specimen. Any amount of blood greater than five cells per microliter of urine is considered clinically significant; visual examination cannot be relied upon to detect the presence of blood. Microscopic examination of the urinary sediment shows intact red blood cells, but free hemoglobin produced either by hemolytic disorders or lysis of red blood cells is not detected. Therefore, chemical tests for hemoglobin provide the most accurate mean for determining the presence of blood. Once blood has been detected, the microscopic examination can be used to differentiate between hematuria and hemoglobinuria.

Chemical tests for blood use the pseudoperoxidase activity of hemoglobin to catalyze a reaction between the heme component of both hemoglobin and myoglobin and the chromogen (a substance that acquires colour after a chemical reaction) tetramethylbenzidine to produce an oxidized chromogen, which has a green-blue colour. Reagent strip manufacturers incorporate peroxide, and tetramethylbenzidine, into the blood testing area. Two colour charts are provided that correspond to the reactions that occur with hemoglobinuria, myoglobinuria and hematuria (RBCs). In the presence of free hemoglobin/myoglobin, uniform colour ranging from a negative yellow through green to a strongly positive green-blue appears on the pad. In contrast, intact red blood cells are lysed when they come in contact with the pad, and the liberated hemoglobin produces an isolated reaction that results in a speckled pattern on the pad. Reagent strip tests can detect concentrations as low as five red blood cells per microliter; however, care must be taken when comparing these figures with the actual microscopic values, because the absorbent nature of the pad attracts some of urine. The terms trace, small, moderate, and large (or trace, 1+, 2+, and 3+) are used for reporting.

False-positive reactions due to menstrual contamination may be seen. They also occur if strong oxidizing detergents are present in the specimen container. Vegetable peroxidase and bacterial enzymes, including an _Escherichia coli_ peroxidase, may also cause false-positive reactions. Therefore, sediments containing bacteria should be checked closely for the presence of red blood cells. Traditionally, ascorbic acid (vitamin C) has been associated with false-negative reagent strip reactions for blood. Both Multistix and Chemstrip have modified their reagent strips to reduce this interference to very high levels of ascorbic acid, and Chemstrip overlays the reagent pad with an iodate-impregnated mesh that oxidizes the ascorbic acid prior to its reaching the reaction pad. False-negative reactions can result when urine with a high specific gravity contains crenated red blood cells that do not lyse when they come in contact with the reagent pad. Decreased reactivity may also be seen when formalin is used as a preservative or when the hypertension medication captopril or high concentration of nitrite are present. Red blood cells settle to the bottom of the specimen container, and failure to mix the specimen prior to testing causes a falsely decreased reading.[\[10\]](https://en.wikipedia.org/wiki/Urine_test_strip#cite_note-10)

## Diseases identified

With the aid of routine examinations early symptoms of the following four groups can be identified:

- Diseases of the kidneys and the urinary tract
- Carbohydrate metabolism disorders (diabetes mellitus)
- Liver diseases and haemolytic disorders
- Urinary infections

### Urinary tract

Screening parameters: Many renal and urinary tract diseases may be [asymptomatic](https://en.wikipedia.org/wiki/Asymptomatic "Asymptomatic") for a long period of time. Routine urinalysis is recommended as a basic yet fundamental step in identifying [renal](https://en.wikipedia.org/wiki/Renal "Renal") damage and/or [urinary tract disease](https://en.wikipedia.org/wiki/Urinary_tract_disease?action=edit&redlink=1 "Urinary tract disease") at an early stage, especially in high-risk populations such as [diabetics](https://en.wikipedia.org/wiki/Diabetics "Diabetics"), the [hypertensive](https://en.wikipedia.org/wiki/Hypertensive "Hypertensive"), [African Americans](https://en.wikipedia.org/wiki/African_Americans "African Americans"), [Polynesians](https://en.wikipedia.org/wiki/Polynesians "Polynesians"), and those with a [family history](https://en.wikipedia.org/wiki/Heredity "Heredity").[\[11\]](https://en.wikipedia.org/wiki/Urine_test_strip#cite_note-11)

Specific kidney and urinary tract diseases that can be identified include: [chronic kidney disease](https://en.wikipedia.org/wiki/Chronic_kidney_disease "Chronic kidney disease"), [glomerulonephritis](https://en.wikipedia.org/wiki/Glomerulonephritis "Glomerulonephritis"), [proteinuria](https://en.wikipedia.org/wiki/Proteinuria "Proteinuria") and [haematuria](https://en.wikipedia.org/wiki/Haematuria "Haematuria").

#### Protein testing

Of the routine chemical tests performed on urine, the most indicative of renal disease is the protein determination. Proteinuria is often associated with early renal disease, making the urinary protein test an important part of any physical examination. Normal urine contains very little protein, usually less than 100–300mg/L or 100mg per 24 hours is excreted. This protein consists primarily of low-molecular-weight serum proteins that have been filtered by the glomerulus and proteins produced in the genitourinary tract. Due to its low molecular weight, albumin is the major serum protein found in the plasma, the normal urinary albumin content is low because the majority of albumin presented in the glomerulus is not filtered, and much of the filtered albumin is reabsorbed by the tubules. Other proteins include small amounts of serum and tubular microglobulins. Uromodulin produced by the renal tubular epithelial cells and proteins from prostatic, seminal, and vaginal secretions. Uromodulin is routinely produced in the distal convoluted tube, and forms the matrix of casts.

Traditional reagent strip testing for protein uses the principle of the protein error of indicators to produce a visible colorimetric reaction. Contrary to the general belief that indicators produce specific colours in response to particular pH levels, certain indicators change colour in the presence of protein even though the pH of the medium remains constant. This is so because protein accepts hydrogen ions from the indicator. The test is more sensitive to albumin because albumin contains more amino groups to accept the hydrogen ions than other proteins. Depending on the manufacturer, the protein area of the strip contains different chemicals. Multistix contains tetrabromophenol blue and Chemstrip contains 3’,3”,5’,5”-tetrachlorophenol, 3,4,5,6-tetrabromosulfonphthalein. Both contain an acid buffer to maintain the pH at a constant level. At a pH level of 3, both indicators appear yellow in the absence of protein. However, as the protein concentration increases, the colour progresses through various shades of green and finally to blue. Readings are reported in terms of negative, trace, 1+, 2+, 3+ and 4+ or the semi-quantitative values of 30, 100, 300 or 2000mg/dL corresponding to each colour change. Trace values are considered to be less than 30mg/dL. Interpretation of trace readings can be difficult.[\[12\]](https://en.wikipedia.org/wiki/Urine_test_strip#cite_note-12)

**Indicator-H+(Yellow) \+ Protein → Indicator(Blue-green) \+ Protein-H+**

The major source of error with reagent strips occurs with highly buffered alkaline urine that overrides the acid buffer system, producing a rise in pH and a colour change unrelated to protein concentration. Likewise, a technical error of allowing the reagent pad to remain in contact with the urine for a prolonged period may remove the buffer. False-positive readings are obtained when the reaction does not take place under acidic conditions. Highly pigmented urine and contamination of the container with quaternary ammonium compounds, detergents and antiseptics also cause false-positive readings. A false-positive trace reading may occur in specimens with a high specific gravity.
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

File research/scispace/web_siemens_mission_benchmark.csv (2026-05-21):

title,url,markdown,author,description,date,image,favicon
Urine analyzer - All medical device manufacturers,https://www.medicalexpo.com/medical-manufacturer/urine-analyzer-402.html,"# Urine analyzers
51
companies
\| 117
products
- My filters
for clinical diagnostic
Delete all
- What’s new?
- ## Manufacturers
  - 7
  - 77 Elektronika (4)
  - A
  - A. Menarini Diagnostics (1)
  - Abbott (1)
  - Accurex Biomedical Pvt. Ltd. (1)
  - Agappe Diagnostics Switzerland GmbH (2)
  - ALPHATEC SCIENTIFIC (1)
  - Alta DiagnoTech (1)
  - Analyticon Biotechnologies GmbH (3)
  - Arkray (5)
  - B
  - Beckman Coulter (3)
  - BILIMSEL TIBBI ÜRÜNLER (3)
  - Biobase (3)
  - Bioway Biological Technology Co.,Ltd (3)
  - C
  - Callegari (1)
  - Changchun Wancheng Bio-Electron Co., Ltd. (2)
  - CHENGDU EMPSUN MEDICAL CO.,LTD (3)
  - ChungDo Pharm. Co., Ltd. (3)
  - Clinical Design (1)
  - Contec Medical Systems (2)
  - Cormay Diagnostics (2)
  - CPM SAS (2)
  - D
  - Dialab (1)
  - DIRUI Industrial (10)
  - E
  - EKF Diagnostics (1)
  - ERBA Diagnostics Mannheim (4)
  - Erba Lachema (2)
  - G
  - GUANGZHOU EXCBIO TECHNOLOGY CO.,LTD (2)
  - Guilin Urit Electronic Group Co.,Ltd (12)
  - H
  - HTI Medical Inc. (2)
  - I
  - Infitek (1)
  - J
  - Jiangsu Konsung Medical Equipment (1)
  - Jinan Kinghawk Technology Co., Ltd. (1)
  - M
  - MACHEREY-NAGEL (2)
  - Medicalsystem Biotechnology Co., Ltd. (2)
  - Menarini Diagnostics (1)
  - P
  - Paramedical srl (3)
  - R
  - Reetoo (1)
  - S
  - Seeuco Electronics Technology (1)
  - Shenzhen Prokan Electronics Inc (1)
  - Shenzhen Render Biotech Co., Ltd. (1)
  - Shinova Medical Co., Ltd (1)
  - Siemens Healthineers - Laboratory Diagnostics (4)
  - Spinreact (2)
  - Sysmex Europe (4)
  - T
  - TENKO MEDICAL SYSTEM CORP (1)
  - U
  - U-Therm International (H.K.) Limited (1)
  - W
  - Wama Diagnostica (1)
  - X
  - Xindray Medical (1)
  - Y
  - YSENMED (2)
  - Z
  - Zhuhai Keyu Biological Engineering Co., Ltd. (3)
  - zybio Inc. (1)
Submit
- ## Operation
  - automatic(87)
  - semi-automatic(21)
  - point-of-care(8)
  - fully automatic(1)
Submit
- ## Applications
  - for clinical diagnostic(117)
  - veterinary(8)
  - sample preparation(2)
Submit
- ## Configuration
  - benchtop(78)
  - portable(19)
  - compact(16)
  - modular(4)
  - integrated system(1)
Submit
- ## Analysis modes
  - colorimetric(6)
  - fluorescence(1)
Submit
- ## Sampling mode
  - continuous access(3)
  - STAT(2)
Submit
- ## Options
  - with touch screen(29)
  - USB(19)
  - with barcode reader(16)
  - wireless(6)
  - microscope(5)
  - high-throughput(1)
Submit
![](https://img.medicalexpo.com/media/ps/images/me/exhibit/exhibit-logo-thumbnail.svg)
exhibit your products
& reach your clients in one place, all year round
Exhibit with us
{{#pushedProductsPlacement4.length}}
{{#each pushedProductsPlacement4}}
{{/each}}
{{/pushedProductsPlacement4.length}}
{{#pushedProductsPlacement5.length}}
{{#each pushedProductsPlacement5}}
{{/each}}
{{/pushedProductsPlacement5.length}}
![fully automatic urine analyzer](https://img.medicalexpo.com/images_me/photo-m2/67523-20702013.jpg)
[![Agappe Diagnostics Switzerland GmbH](<Base64-Image-Removed>)](https://www.medicalexpo.com/prod/agappe-diagnostics-switzerland-gmbh-67523.html ""Agappe Diagnostics Switzerland GmbH"")[**fully automatic urine analyzerMispa U280**\\
benchtopmicroscope](https://www.medicalexpo.com/prod/agappe-diagnostics-switzerland-gmbh/product-67523-1200469.html ""fully automatic urine analyzer"")
Contact
fully automatic urine analyzer
Mispa U280
... Mispa U280 is a Fully automated and integrated
**Urine** **Analyzer**, which can analyze
**urine** sample in totality. Mispa U280 analyses
**urine** for Physical/ Chemical and microscopic parameters. ...
Compare this productRemove from comparison tool
![semi-automatic urine analyzer](https://img.medicalexpo.com/images_me/photo-m2/67523-20702005.jpg)
![Agappe Diagnostics Switzerland GmbH](<Base64-Image-Removed>)[**semi-automatic urine analyzerMispa Uriskan 100 Plus**\\
compact](https://www.medicalexpo.com/prod/agappe-diagnostics-switzerland-gmbh/product-67523-961516.html ""semi-automatic urine analyzer"")
Contact
semi-automatic urine analyzer
Mispa Uriskan 100 Plus
... Superior Automation in
**urine** **analyzer** The
**urine** **analyzer**, Mispa Uriskan 100 Plus, is a Semi-Automated
**Urine** Chemistry
**Analyzer** that can process up ...
Compare this productRemove from comparison tool
![semi-automatic urine analyzer](https://img.medicalexpo.com/images_me/photo-m2/68321-21265512.jpg)
[![EKF Diagnostics](<Base64-Image-Removed>)](https://www.medicalexpo.com/prod/ekf-diagnostics-68321.html ""EKF Diagnostics"")[**semi-automatic urine analyzerUri-Trak® 120M**\\
benchtop](https://www.medicalexpo.com/prod/ekf-diagnostics/product-68321-1185382.html ""semi-automatic urine analyzer"")
Contact
semi-automatic urine analyzer
Uri-Trak® 120M
... The Uri-Trak® 120M
**Urine** **Analyzer** provides accuracy and consistency in
**urine** chemistry testing.
Uri-Trak® 120M
**Urine** **Analyzer** allows physician offices and laboratories ...
Compare this productRemove from comparison tool
![portable urine analyzer](<Base64-Image-Removed>)
[![Contec Medical Systems](<Base64-Image-Removed>)](https://www.medicalexpo.com/prod/contec-medical-systems-68095.html ""Contec Medical Systems"")[**portable urine analyzerBC401**\\
point-of-careUSBBluetooth](https://www.medicalexpo.com/prod/contec-medical-systems/product-68095-713762.html ""portable urine analyzer"")
€68
 -
€110
Price excl. tax \*
Contact
portable urine analyzer
BC401
... BC401
**Urine** **Analyzer** is a high-precision, intellectual instrument which is researched and developed basing on modern optics, electronics, computer science and other advanced technologies for clinical inspection of
**urine**. ...
Compare this productRemove from comparison tool
![semi-automatic urine analyzer](<Base64-Image-Removed>)
![Contec Medical Systems](<Base64-Image-Removed>)[**semi-automatic urine analyzerBC400**\\
benchtop](https://www.medicalexpo.com/prod/contec-medical-systems/product-68095-430941.html ""semi-automatic urine analyzer"")
€120
 -
€170
Price excl. tax \*
Contact
semi-automatic urine analyzer
BC400
... BC400
**Urine** **Analyzer** is a high-precision, intellectual instrument which is researched and developed basing on modern optics, electronics, computer science and other advanced technologies for clinical inspection of
**urine**. ...
Compare this productRemove from comparison tool
![semi-automatic urine analyzer](<Base64-Image-Removed>)
[![Alta DiagnoTech](<Base64-Image-Removed>)](https://www.medicalexpo.com/prod/alta-diagnotech-4610660.html ""Alta DiagnoTech"")[**semi-automatic urine analyzerDIRUI**\\
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

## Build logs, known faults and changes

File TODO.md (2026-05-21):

# Urine Analyzer Lite — Project TODO

> **Legend:** ✅ Done &nbsp;|&nbsp; 🔲 Pending &nbsp;|&nbsp; 🔄 In Progress

---

## Hardware — PCB / Schematic

> ⚠️ STAGE 4 GATE: see `hardware/ENGINEERING_REVIEW.md` + `hardware/POWER_BUDGET.md`.
> The existing `.kicad_sch` is a graphical mock-up with NO netlist. config.h / Blueprint / BOM
> disagree on motor driver, I2C pins, motor/HX711/printer pins, display, and the 9V rail.
> Resolve all 🔴 items + sign off the master pin map before any layout.

- 🔲 **Engineer: resolve 🔴 items + approve master pin map (ENGINEERING_REVIEW §3)**
- 🔲 **Fix config.h: SCL≠GPIO22 (invalid on S3), printer RX off GPIO19 (USB), UV-C off GPIO3 (strap)**
- 🔲 **Add TCA9548A I2C mux + 3.3V regulator to BOM (two TCS34725 clash at 0x29; no 3V3 rail)**
- 🔲 **Decide display: ESP32-S3 cannot drive MIPI-DSI — pick SPI TFT / RGB / OLED / new host**
- ✅ Netlist generated from master pin map → `hardware/netlist/` (.net + NETLIST.md)
- ✅ Schematic: real library symbols (jellybeans) + real footprints, ERC 0 errors, netlist 39/39
- ✅ Starting PCB generated → `hardware/pcb/` (31 fp placed + nets, schematic-parity 0, unrouted)
- 🔲 Engineer: confirm module header pin ORDER vs datasheets (footprints.py)
- 🔲 Engineer: place + route, power planes, mounting holes, DRC→0, export Gerbers
- 🔲 Open schematic in KiCad EDA and visually verify all nets
- 🔲 Assign real KiCad symbol library parts to each component
- 🔲 Add ERC (Electrical Rules Check) violations resolution
- 🔲 Design custom PCB layout in KiCad PCB editor
- 🔲 Add power planes (GND, 3V3, 5V)
- 🔲 Route high-current traces for motor and printer (≥1 mm width)
- 🔲 Add mounting holes (4× M3) aligned to chassis stand-offs
- 🔲 Run DRC (Design Rules Check) — target 0 errors
- 🔲 Export Gerber files and BOM for fabrication (JLCPCB / PCBWay)
- 🔲 Order 5× prototype PCBs

---

## Hardware — CAD / Mechanical

- ✅ OpenSCAD source file (`hardware/cad/main_chassis.scad`)
- 🔲 Render all modules to STL (`openscad -o part.stl main_chassis.scad -D 'part="chassis_base"'` etc.)
- 🔲 Review prints for dimensional accuracy against component datasheets
- 🔲 Verify ESP32-S3-DevKitC-1 footprint fits MCU tray (68.6 × 28.8 mm)
- 🔲 Verify CSN-A2 fits printer bracket (57.5 × 37 × 40 mm)
- 🔲 Test fit belt tensioner with 625ZZ idler bearing
- 🔲 Confirm limit switch bracket adjustability range ≥ 10 mm
- 🔲 Print optical chamber in black PLA — light-tight test with torch
- 🔲 Glue or press-fit frosted acrylic diffuser into chamber slot
- 🔲 Print dipstick tray — verify 6 mm strip fits without play
- 🔲 Print final chassis with PETG; install heat-set inserts
- 🔲 Add 2° draft angles to all vertical walls for injection-mould readiness

---

## Firmware

- ✅ `config.h` — all pin assignments and tunable constants
- ✅ `sensors.h` — TCS34725, ADS1115, SHT31, BH1750, HX711 drivers
- ✅ `motor.h` — N20 encoder-based motion control + homing
- ✅ `analysis.h` — HSV-based pad classification (10 analytes)
- ✅ `printer.h` — CSN-A2 ESC/POS thermal printer output
- ✅ `main.ino` — state machine: IDLE → HOMING → SCANNING → PRINTING → STERILIZING
- 🔲 Flash firmware to hardware and test boot
- 🔲 Calibrate HX711 scale factor with known weight
- 🔲 Calibrate TCS34725 against Spectralon white standard (update `CAL_R/G/B_WHITE`)
- 🔲 Calibrate `TICKS_PER_PAD` with physical dipstick (measure real pad pitch)
- 🔲 Validate HSV hue ranges in `analysis.h` using positive/negative reference strips
- 🔲 Implement display UI (LVGL or LovyanGFX on DSI LCD)
- 🔲 Add Bluetooth/Wi-Fi result upload (optional)
- 🔲 Implement OTA firmware update
- 🔲 Add watchdog timer and brownout detection
- 🔲 Write unit tests for `rgb_to_hsv()` and `classify_pad()`

---

## BOM / Procurement

- ✅ BOM CSV (`bom/bom.csv`) — 40 line items, estimated total ≈ $387 per unit
- 🔲 Obtain quotes from Indian distributors (Rhydo, Robocraze, Electronicscomp)
- 🔲 Source TCS34725 from Adafruit or equivalent (check availability)
- 🔲 Procure Labsphere Spectralon calibration standard (long lead time)
- 🔲 Verify CSN-A2 printer stock and 58mm paper availability locally
- 🔲 Confirm Waveshare 4.3in DSI LCD DSI compatibility with ESP32-S3
- 🔲 Bulk pricing target: < $250 per unit at 50-unit volume

---

## Integration & Testing

- 🔲 Power-on test: verify 3V3 and 5V rails under load
- 🔲 I2C scan — confirm all 5 devices at expected addresses
- 🔲 Motor homing test — both limit switches trigger correctly
- 🔲 Full scan cycle with blank dipstick — no crashes, 10 pads detected
- 🔲 Full scan cycle with positive control strip — correct analyte results
- 🔲 Thermal print output matches on-screen report
- 🔲 UV-C sterilization cycle runs for 10 s and shuts off
- 🔲 Weight sensor detects cup placement > 1 g threshold
- 🔲 Environmental envelope test: 15–35 °C, 20–80% RH

---

## Documentation

- ✅ Assembly guide template (`hardware/schematic/` + `GUIDE.md` in source data)
- 🔲 Write complete assembly guide with photos
- 🔲 Write calibration SOP (white standard → pad validation)
- 🔲 Write operator quick-start card (print on 58mm paper)
- 🔲 Add troubleshooting section (I2C errors, motor faults, print jams)
- 🔲 Create block diagram image for README

---

## Regulatory / Quality — Stage 0 Foundation (see `regulatory/`)

- ✅ Target Product Profile + Intended Use (`regulatory/00_...`)
- ✅ CDSCO classification & pathway — best-guess Class B (`regulatory/01_...`)
- ✅ Applicable standards matrix (`regulatory/02_...`)
- ✅ ISO 14971 risk management file — skeleton (`regulatory/03_...`)
- ✅ Preliminary FTO patent search — optics (`regulatory/04_...`)
- 🔲 **DECIDE: proprietary strips vs commercial strips** (gates scope)
- 🔲 **Confirm CDSCO class via regulatory consultant pre-submission**
- 🔲 **DECIDE: keep or drop UV-C sterilization** (IEC 62471 burden vs benefit)
- 🔲 Identify predicate device(s)
- 🔲 ISO 13485 QMS alignment checklist
- 🔲 Re-run FTO on Lens.org/Espacenet + check patent legal status/expiry
- 🔲 CE / 510(k) pathway assessment (export, later)

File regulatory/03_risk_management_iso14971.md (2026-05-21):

# Risk Management File (ISO 14971) — Urine Analyzer Lite

> Stage 0 Foundation document. Status: DRAFT skeleton (2026-05-21).
> This is the seed of the living risk file. Populate severity/probability against a defined
> scale, link each control to a verification, and close the file at design freeze (Stage 5)
> before validation. Per the project hard-gate: validating an unfrozen design = repeat work.

## 1. Risk policy (to define)
- [ ] Define severity scale (e.g. 1 Negligible → 5 Catastrophic)
- [ ] Define probability scale (e.g. 1 Improbable → 5 Frequent)
- [ ] Define risk acceptability matrix and overall residual-risk acceptance criteria

## 2. Intended use & reasonably foreseeable misuse (from TPP)
- Intended: trained personnel, clinic POC, semi-quantitative urinalysis aid to diagnosis.
- Foreseeable misuse: expired/wrong strip, mis-timed read, wet/contaminated optics,
  ambient light ingress, reading a non-compatible strip, lay use outside intended population.

## 3. Hazard analysis / preliminary FMEA

> S/P/RPN left blank — to be scored against the policy scale. "→" = required risk control.

| # | Hazard / cause | Potential harm | Risk control (→) | Verify in |
|---|---|---|---|---|
| H1 | **UV-C (275 nm) exposure** to operator eyes/skin (lid open, interlock fails) | Photokeratitis, skin burn | → Mechanical interlock so UV-C cannot fire unless chamber closed; shielding; IEC 62471 assessment; consider removing UV-C | Stage 7/8 |
| H2 | **Incorrect analyte result** (mis-calibration, drift, lighting, wrong hue table) | Missed/incorrect diagnosis | → White-standard calibration SOP; internal reference/QC strip; ambient-light sensor compensation (BH1750); reportable-range limits; IFU "aid to diagnosis only" | Stage 6 |
| H3 | **Reading an incompatible / expired strip** | Wrong result | → Strip compatibility declared in IFU; (optional) strip-type detection; expiry warning in workflow | Stage 6/11 |
| H4 | **Ambient light / optical contamination** (fingerprints, urine on optics) | Result error | → Light-tight chamber (black PLA, verified); cleaning SOP; self-check on white standard each session | Stage 5/6 |
| H5 | **Biohazard** — urine contamination of device/operator | Infection exposure | → Disposable strip handling; cleanable surfaces; decontamination SOP; no free-liquid handling | Stage 8/11 |
| H6 | **Electrical safety** — LiPo fault, charger fault, mains (if any) | Burn/fire/shock | → TP4056 protection + protected cell; IEC 61010-1 compliance; fusing; thermal cutoff | Stage 7 |
| H7 | **LiPo thermal runaway** (charge fault, heat near printer/UV) | Fire | → Protected cell, charge temp limits, physical separation from heat sources, brownout/thermal monitoring | Stage 7 |
| H8 | **Mechanical pinch / motor** (N20 strip transport) | Minor injury | → Enclosed transport, low-torque motor, limit switches, no exposed moving parts | Stage 5/8 |
| H9 | **Thermal printer burn** (printhead hot) | Minor burn | → Enclosure, IFU warning | Stage 7 |
| H10 | **Software failure** — hang, misclassification, silent wrong result | Wrong/no result without operator awareness | → Watchdog + brownout (in TODO); IEC 62304 process; unit tests for `rgb_to_hsv`/`classify_pad`; result plausibility checks; fail-safe = no result rather than wrong result | Stage 4/8 |
| H11 | **Use error** — mis-timed read, wrong strip orientation | Wrong result | → Guided UI workflow; fixed motorized timing (removes manual timing error); IEC 62366 study | Stage 8 |
| H12 | **Cybersecurity** (if Wi-Fi/BT added) | Data integrity/privacy | → If connectivity added: threat model, secure OTA, no PII in transit without protection | Stage 8 (conditional) |

## 4. Notable design-level observations
- The **motorized fixed-timing read is a safety strength** — it removes the operator-timing
  error that plagues manual visual dipstick reading. Capture this as a risk-reducing feature.
- **UV-C (H1) is the highest-novelty hazard** and the main reason to reconsider that feature.
- **Fail-safe principle to adopt:** on any sensor/calibration/plausibility failure, the device
  must *withhold* a result (and say so), never print a guessed one.

## 5. Next
- [ ] Score all hazards; compute initial vs residual risk.
- [ ] Link each control to a specific verification/test (traceability).
- [ ] Add overall residual-risk / benefit-risk conclusion at design freeze.

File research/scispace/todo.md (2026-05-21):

# TODO
## Scholarly literature search
- [x] Search scholarly literature for technology overview
## Web research and scraping
- [x] Activate web-search-and-scrape skill
- [x] Search web for electronics and optical sensors
- [x] Search web for Indian regulatory and market context
## Report generation and conversion
- [x] Generate comprehensive markdown report with citations
- [x] Convert markdown report to PDF file

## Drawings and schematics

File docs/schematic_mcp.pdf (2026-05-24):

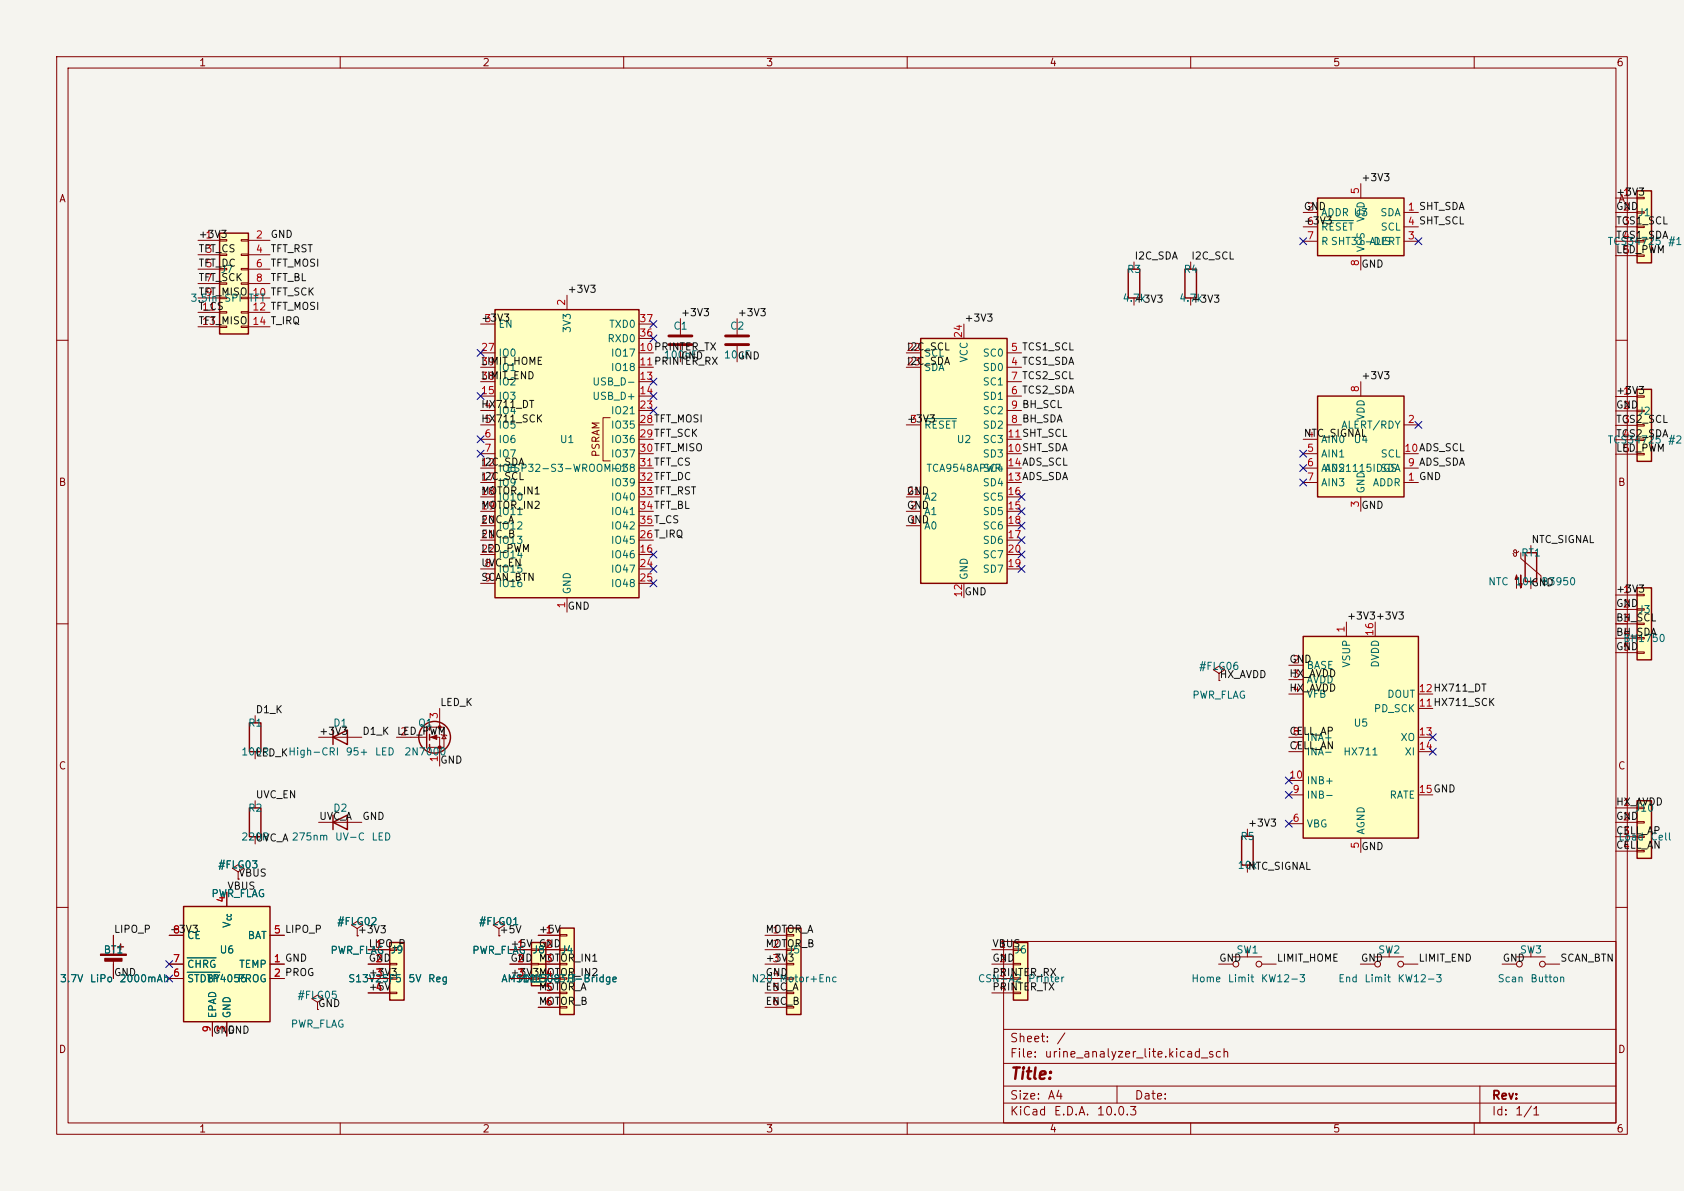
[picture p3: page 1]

XI 14 RATE 15 DVDD 16 U5 HX711 PSRAM GND

Size: A4 | Rev:
KiCad E.D.A. 10.0.3 | Id: 1/1

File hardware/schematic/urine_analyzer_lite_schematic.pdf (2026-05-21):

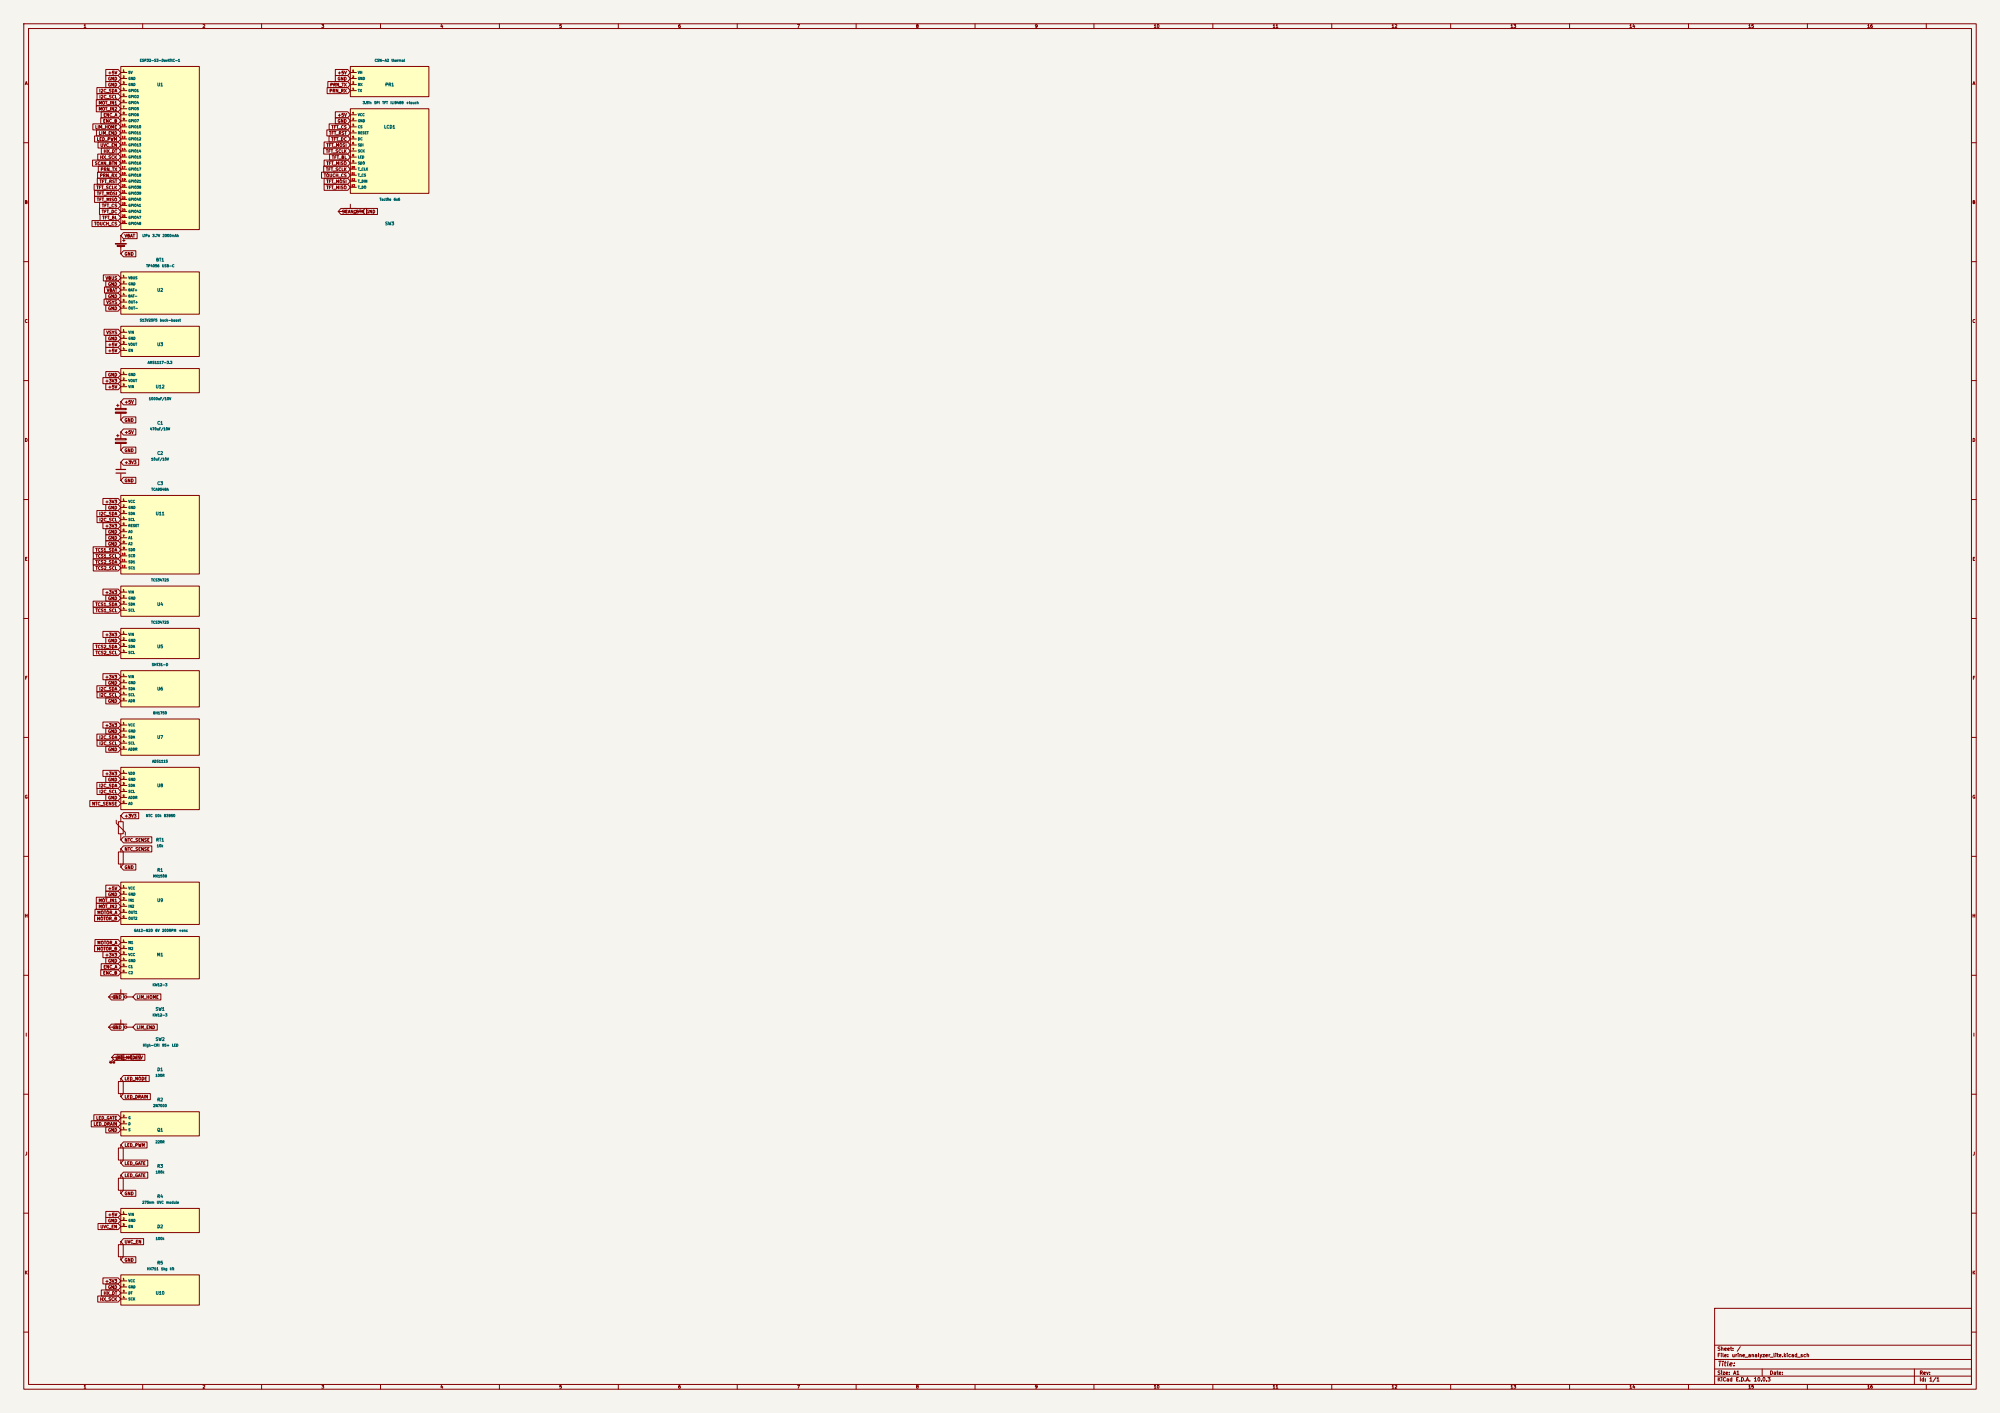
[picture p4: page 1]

Size: A1 | Rev:
KiCad E.D.A. 10.0.3 | Id: 1/1

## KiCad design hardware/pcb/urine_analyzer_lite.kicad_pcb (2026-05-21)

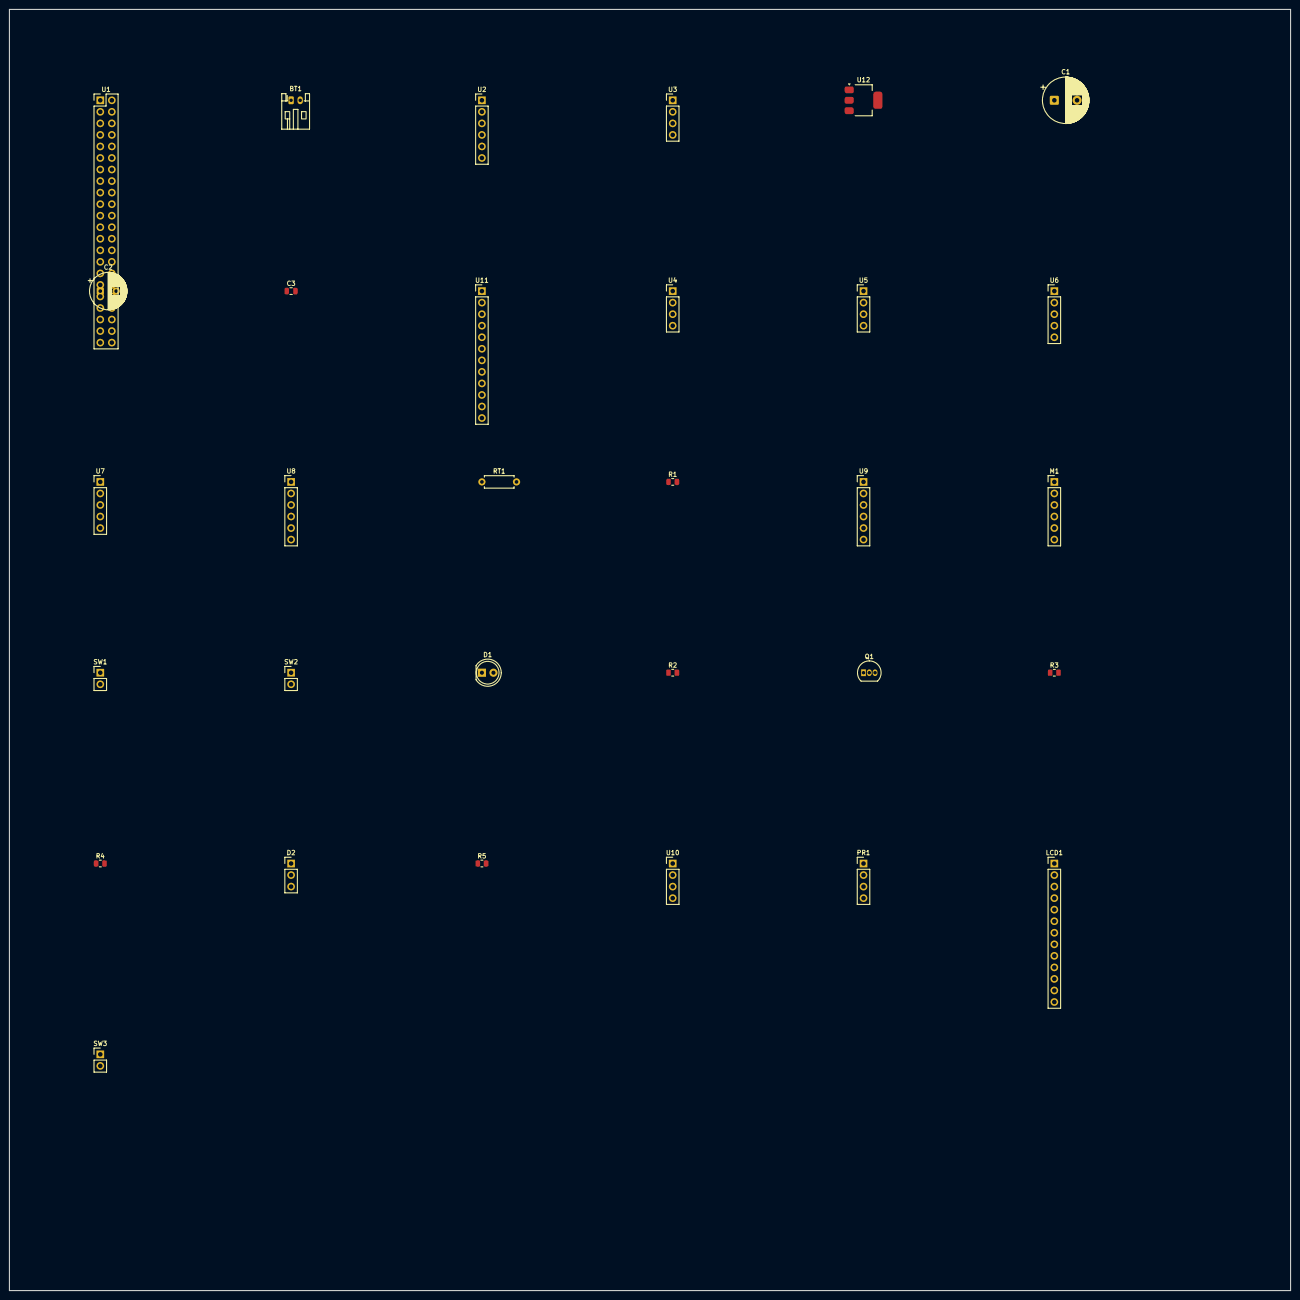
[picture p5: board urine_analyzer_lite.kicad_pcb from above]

Board: 2 copper layers, 282.0 x 282.0 mm, 31 parts (0 on the bottom side), 38 nets, no tracks yet.

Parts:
BT1: LiPo 3.7V 2000mAh; JST_PH_S2B-PH-K_1x02_P2.00mm_Horizontal
C1: 1000uF/10V; CP_Radial_D10.0mm_P5.00mm
C2: 470uF/10V; CP_Radial_D8.0mm_P3.50mm
C3: 10uF/10V; C_0805_2012Metric
D1: High-CRI 95+ LED; LED_D5.0mm_Clear
D2: 275nm UVC module; PinHeader_1x03_P2.54mm_Vertical
LCD1: 3.5in SPI TFT ILI9488 +touch; PinHeader_1x13_P2.54mm_Vertical
M1: GA12-N20 6V 200RPM +enc; PinHeader_1x06_P2.54mm_Vertical
PR1: CSN-A2 thermal; PinHeader_1x04_P2.54mm_Vertical
Q1: 2N7000; TO-92_Inline
R1: 10k; R_0805_2012Metric
R2: 100R; R_0805_2012Metric
R3: 220R; R_0805_2012Metric
R4, R5: 100k; R_0805_2012Metric
RT1: NTC 10k B3950; R_Axial_DIN0207_L6.3mm_D2.5mm_P7.62mm_Horizontal
SW1, SW2: KW12-3; PinHeader_1x02_P2.54mm_Vertical
SW3: Tactile 6x6; PinHeader_1x02_P2.54mm_Vertical
U1: ESP32-S3-DevKitC-1; PinHeader_2x22_P2.54mm_Vertical
U2: TP4056 USB-C; PinHeader_1x06_P2.54mm_Vertical
U3: S13V25F5 buck-boost; PinHeader_1x04_P2.54mm_Vertical
U4, U5: TCS34725; PinHeader_1x04_P2.54mm_Vertical
U6: SHT31-D; PinHeader_1x05_P2.54mm_Vertical
U7: BH1750; PinHeader_1x05_P2.54mm_Vertical
U8: ADS1115; PinHeader_1x06_P2.54mm_Vertical
U9: MX1508; PinHeader_1x06_P2.54mm_Vertical
U10: HX711 1kg kit; PinHeader_1x04_P2.54mm_Vertical
U11: TCA9548A; PinHeader_1x12_P2.54mm_Vertical
U12: AMS1117-3.3; SOT-223-3_TabPin2

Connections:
+3V3: C3.1, M1.3, RT1.1, U4.1, U5.1, U6.1, U7.1, U8.1, U10.1, U11.1, U11.5, U12.2
+5V: C1.1, C2.1, D1.2, D2.1, LCD1.1, PR1.1, U1.1, U3.3, U3.4, U9.1, U12.3
ENC_A: M1.5, U1.8
ENC_B: M1.6, U1.9
GND: BT1.2, C1.2, C2.2, C3.2, D2.2, LCD1.2, M1.4, PR1.2, Q1.1, R1.2, R4.2, R5.2, SW1.1, SW2.1, SW3.2, U1.2, U1.3, U2.2, U2.4, U2.6, U3.2, U4.2, U5.2, U6.2, U6.5, U7.2, U7.5, U8.2, U8.5, U9.2, U10.2, U11.2, U11.6, U11.7, U11.8, U12.1
HX_DT: U1.14, U10.3
HX_SCK: U1.15, U10.4
I2C_SCL: U1.5, U6.4, U7.4, U8.4, U11.4
I2C_SDA: U1.4, U6.3, U7.3, U8.3, U11.3
LED_DRAIN: Q1.3, R2.2
LED_GATE: Q1.2, R3.2, R4.1
LED_NODE: D1.1, R2.1
LED_PWM: R3.1, U1.12
LIM_END: SW2.2, U1.11
LIM_HOME: SW1.2, U1.10
MOTOR_A: M1.1, U9.5
MOTOR_B: M1.2, U9.6
MOT_IN1: U1.6, U9.3
MOT_IN2: U1.7, U9.4
NTC_SENSE: R1.1, RT1.2, U8.6
PRN_RX: PR1.4, U1.18
PRN_TX: PR1.3, U1.17
SCAN_BTN: SW3.1, U1.16
TCS1_SCL: U4.4, U11.10
TCS1_SDA: U4.3, U11.9
TCS2_SCL: U5.4, U11.12
TCS2_SDA: U5.3, U11.11
TFT_BL: LCD1.8, U1.25
TFT_CS: LCD1.3, U1.23
TFT_DC: LCD1.5, U1.24
TFT_MISO: LCD1.9, LCD1.13, U1.22
TFT_MOSI: LCD1.6, LCD1.12, U1.21
TFT_RST: LCD1.4, U1.19
TFT_SCLK: LCD1.7, LCD1.10, U1.20
TOUCH_CS: LCD1.11, U1.26
UVC_EN: D2.3, R5.1, U1.13
VBAT: BT1.1, U2.3
VSYS: U2.5, U3.1

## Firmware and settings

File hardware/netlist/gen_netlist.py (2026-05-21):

#!/usr/bin/env python3
"""
Netlist generator for Urine Analyzer Lite (Design A: ESP32-S3 + dual TCS34725).

Single source of truth = the master pin map in firmware/main/config.h
(documented in hardware/ENGINEERING_REVIEW.md §3). Emits:
  - urine_analyzer_lite.net   KiCad legacy netlist (File > Import Netlist in Pcbnew)
  - NETLIST.md                human-readable connection table for review

NOTE: This describes intended connectivity for engineer verification. Real KiCad footprints
are assigned via footprints.py (modules use 2.54mm pin headers — verify pin ORDER against each
module datasheet). Decoupling/bulk caps are included where load behavior demands them; add
per-rail 100 nF at layout as standard practice.

Run: python3 gen_netlist.py
"""

import datetime, sys, os

# ── Component model ───────────────────────────────────────────────────────────
# Each component: ref, value, footprint(placeholder), description, and pins:
#   { pin_number: (pin_name, net_name) }
# Nets are inferred by grouping all (ref, pin) that share a net_name.

COMPONENTS = [
    ("U1", "ESP32-S3-DevKitC-1", "Module:ESP32-S3-DevKitC-1_header_2x22",
     "Main MCU (USB-CDC enabled)", {
        "5V":   ("5V",     "+5V"),
        "GND1": ("GND",    "GND"),
        "GND2": ("GND",    "GND"),
        "1":    ("GPIO1",  "I2C_SDA"),
        "2":    ("GPIO2",  "I2C_SCL"),
        "4":    ("GPIO4",  "MOT_IN1"),
        "5":    ("GPIO5",  "MOT_IN2"),
        "6":    ("GPIO6",  "ENC_A"),
        "7":    ("GPIO7",  "ENC_B"),
        "10":   ("GPIO10", "LIM_HOME"),
        "11":   ("GPIO11", "LIM_END"),
        "12":   ("GPIO12", "LED_PWM"),
        "13":   ("GPIO13", "UVC_EN"),
        "14":   ("GPIO14", "HX_DT"),
        "15":   ("GPIO15", "HX_SCK"),
        "16":   ("GPIO16", "SCAN_BTN"),
        "17":   ("GPIO17", "PRN_TX"),
        "18":   ("GPIO18", "PRN_RX"),
        "21":   ("GPIO21", "TFT_RST"),
        "38":   ("GPIO38", "TFT_SCLK"),
        "39":   ("GPIO39", "TFT_MOSI"),
        "40":   ("GPIO40", "TFT_MISO"),
        "41":   ("GPIO41", "TFT_CS"),
        "42":   ("GPIO42", "TFT_DC"),
        "47":   ("GPIO47", "TFT_BL"),
        "48":   ("GPIO48", "TOUCH_CS"),
     }),

    # ── Power path ──
    ("BT1", "LiPo 3.7V 2000mAh", "Connector:JST_PH_2pin", "Main battery", {
        "1": ("+", "VBAT"), "2": ("-", "GND")}),
    ("U2", "TP4056 USB-C", "Module:TP4056_USBC", "LiPo charger (charge path only)", {
        "1": ("VBUS",  "VBUS"),
        "2": ("GND",   "GND"),
        "3": ("BAT+",  "VBAT"),
        "4": ("BAT-",  "GND"),
        "5": ("OUT+",  "VSYS"),
        "6": ("OUT-",  "GND")}),
    ("U3", "S13V25F5 buck-boost", "Module:Pololu_S13V25Fx", "5V 2.5A regulator", {
        "1": ("VIN",  "VSYS"),
        "2": ("GND",  "GND"),
        "3": ("VOUT", "+5V"),
        "4": ("EN",   "+5V")}),   # EN tied high (always on); engineer may gate
    ("U12", "AMS1117-3.3", "Package_TO_SOT_223:SOT-223-3_TabPin2", "3.3V LDO for sensor bus", {
        "1": ("GND",  "GND"),
        "2": ("VOUT", "+3V3"),
        "3": ("VIN",  "+5V")}),
    ("C1", "1000uF/10V", "CP_Radial_D10.0mm_P5.00mm", "Bulk cap at 5V (printer pulse)", {
        "1": ("+", "+5V"), "2": ("-", "GND")}),
    ("C2", "470uF/10V", "CP_Radial_D8.0mm_P3.50mm", "Bulk cap at motor driver", {
        "1": ("+", "+5V"), "2": ("-", "GND")}),
    ("C3", "10uF/10V", "Capacitor_SMD:C_0805", "AMS1117 output cap", {
        "1": ("1", "+3V3"), "2": ("2", "GND")}),

    # ── I2C mux + sensors ──
    ("U11", "TCA9548A", "Package_SO:TSSOP-24_4.4x7.8mm_P0.65mm", "I2C mux (addr 0x70)", {
        "VCC":  ("VCC",  "+3V3"),
        "GND":  ("GND",  "GND"),
        "SDA":  ("SDA",  "I2C_SDA"),
        "SCL":  ("SCL",  "I2C_SCL"),
        "RST":  ("RESET","+3V3"),
        "A0":   ("A0",   "GND"),
        "A1":   ("A1",   "GND"),
        "A2":   ("A2",   "GND"),
        "SD0":  ("SD0",  "TCS1_SDA"),
        "SC0":  ("SC0",  "TCS1_SCL"),
        "SD1":  ("SD1",  "TCS2_SDA"),
        "SC1":  ("SC1",  "TCS2_SCL")}),
    ("U4", "TCS34725", "Module:Adafruit_TCS34725", "RGB sensor #1 (mux ch0)", {
        "VIN": ("VIN", "+3V3"), "GND": ("GND", "GND"),
        "SDA": ("SDA", "TCS1_SDA"), "SCL": ("SCL", "TCS1_SCL")}),
    ("U5", "TCS34725", "Module:Adafruit_TCS34725", "RGB sensor #2 (mux ch1)", {
        "VIN": ("VIN", "+3V3"), "GND": ("GND", "GND"),
        "SDA": ("SDA", "TCS2_SDA"), "SCL": ("SCL", "TCS2_SCL")}),
    ("U6", "SHT31-D", "Module:SHT31_breakout", "Temp/humidity (0x44)", {
        "VIN": ("VIN", "+3V3"), "GND": ("GND", "GND"),
        "SDA": ("SDA", "I2C_SDA"), "SCL": ("SCL", "I2C_SCL"), "ADR": ("ADR", "GND")}),
    ("U7", "BH1750", "Module:BH1750_breakout", "Ambient light (0x23)", {
        "VCC": ("VCC", "+3V3"), "GND": ("GND", "GND"),
        "SDA": ("SDA", "I2C_SDA"), "SCL": ("SCL", "I2C_SCL"), "ADDR": ("ADDR", "GND")}),
    ("U8", "ADS1115", "Module:ADS1115_breakout", "16-bit ADC (0x48)", {
        "VDD":  ("VDD",  "+3V3"), "GND": ("GND", "GND"),
        "SDA":  ("SDA",  "I2C_SDA"), "SCL": ("SCL", "I2C_SCL"),
        "ADDR": ("ADDR", "GND"), "A0": ("A0", "NTC_SENSE")}),
    ("RT1", "NTC 10k B3950", "Resistor_THT:R_Axial_DIN0207", "Optical chamber temp", {
        "1": ("1", "+3V3"), "2": ("2", "NTC_SENSE")}),
    ("R1", "10k", "Resistor_SMD:R_0805", "NTC divider lower leg", {
        "1": ("1", "NTC_SENSE"), "2": ("2", "GND")}),

    # ── Motor + encoder ──
    ("U9", "MX1508", "Module:MX1508_driver", "Dual H-bridge (one channel used)", {
        "VCC": ("VCC", "+5V"), "GND": ("GND", "GND"),
        "IN1": ("IN1", "MOT_IN1"), "IN2": ("IN2", "MOT_IN2"),
        "OUT1": ("OUT1", "MOTOR_A"), "OUT2": ("OUT2", "MOTOR_B")}),
    ("M1", "GA12-N20 6V 200RPM +enc", "Motor:GA12-N20_encoder", "Strip transport motor", {
        "M1": ("M1", "MOTOR_A"), "M2": ("M2", "MOTOR_B"),
        "VCC": ("VCC", "+3V3"), "GND": ("GND", "GND"),
        "C1": ("C1", "ENC_A"), "C2": ("C2", "ENC_B")}),

    # ── Limit switches (NO; other side to GND, MCU uses INPUT_PULLUP) ──
    ("SW1", "KW12-3", "Button_Switch_THT:SW_Limit", "Home limit (active-LOW)", {
        "1": ("COM", "GND"), "2": ("NO", "LIM_HOME")}),
    ("SW2", "KW12-3", "Button_Switch_THT:SW_Limit", "End limit (active-LOW)", {
        "1": ("COM", "GND"), "2": ("NO", "LIM_END")}),

    # ── Illumination LED + MOSFET ──
    ("D1", "High-CRI 95+ LED", "LED_THT:LED_D5.0mm", "Pad illumination", {
        "A": ("A", "+5V"), "K": ("K", "LED_NODE")}),
    ("R2", "100R", "Resistor_SMD:R_0805", "LED current limit", {
        "1": ("1", "LED_NODE"), "2": ("2", "LED_DRAIN")}),
    ("Q1", "2N7000", "Package_TO_SOT_THT:TO-92", "LED PWM low-side switch", {
        "G": ("G", "LED_GATE"), "D": ("D", "LED_DRAIN"), "S": ("S", "GND")}),
    ("R3", "220R", "Resistor_SMD:R_0805", "MOSFET gate series", {
        "1": ("1", "LED_PWM"), "2": ("2", "LED_GATE")}),
    ("R4", "100k", "Resistor_SMD:R_0805", "MOSFET gate pulldown", {
        "1": ("1", "LED_GATE"), "2": ("2", "GND")}),

    # ── UV-C sterilization LED module (assumed integral CC driver) ──
    ("D2", "275nm UVC module", "Module:UVC_LED_module", "Tray sterilization", {
        "VIN": ("VIN", "+5V"), "GND": ("GND", "GND"), "EN": ("EN", "UVC_EN")}),
    ("R5", "100k", "Resistor_SMD:R_0805", "UV-C EN pulldown (OFF at boot)", {
        "1": ("1", "UVC_EN"), "2": ("2", "GND")}),

    # ── Load cell amp ──
    ("U10", "HX711 1kg kit", "Module:HX711_breakout", "Sample weight", {
        "VCC": ("VCC", "+3V3"), "GND": ("GND", "GND"),
        "DT": ("DT", "HX_DT"), "SCK": ("SCK", "HX_SCK")}),

    # ── Thermal printer (5V; see ENGINEERING_REVIEW §2.6) ──
    ("PR1", "CSN-A2 thermal", "Connector:Printer_TTL_3pin", "Report printout", {
        "VH":  ("VH",  "+5V"),
        "GND": ("GND", "GND"),
        "RX":  ("RX",  "PRN_TX"),   # printer RX <- MCU TX
        "TX":  ("TX",  "PRN_RX")}), # printer TX -> MCU RX

    # ── Display: SPI TFT (ILI9488) + XPT2046 touch on shared SPI ──
    ("LCD1", "3.5in SPI TFT ILI9488 +touch", "Connector:TFT_SPI_14pin", "UI display", {
        "VCC":  ("VCC",  "+5V"),
        "GND":  ("GND",  "GND"),
        "CS":   ("CS",   "TFT_CS"),
        "RESET":("RESET","TFT_RST"),
        "DC":   ("DC",   "TFT_DC"),
        "SDI":  ("SDI",  "TFT_MOSI"),
        "SCK":  ("SCK",  "TFT_SCLK"),
        "LED":  ("LED",  "TFT_BL"),
        "SDO":  ("SDO",  "TFT_MISO"),
        "T_CLK":("T_CLK","TFT_SCLK"),
        "T_CS": ("T_CS", "TOUCH_CS"),
        "T_DIN":("T_DIN","TFT_MOSI"),
        "T_DO": ("T_DO", "TFT_MISO")}),

    # ── Scan button ──
    ("SW3", "Tactile 6x6", "Button_Switch_THT:SW_PUSH_6mm", "Scan trigger (active-LOW)", {
        "1": ("1", "SCAN_BTN"), "2": ("2", "GND")}),
]


sys.path.insert(0, os.path.join(os.path.dirname(os.path.abspath(__file__)), ".."))
import footprints as F

def build_nets():
    """net -> list of (ref, pad_number, pin_name). Pad numbers come from footprints.py
    so the netlist matches the schematic pin numbers and the PCB pads."""
    nets = {}
    for ref, _val, _fp, _desc, pins in COMPONENTS:
        for i, (pin_id, (pin_name, net)) in enumerate(pins.items()):
            pad = F.pad_of(ref, pin_id, i + 1)
            nets.setdefault(net, []).append((ref, pad, pin_name))
    return dict(sorted(nets.items()))


def emit_kicad_net(path):
    ts = datetime.datetime.now().strftime("%Y-%m-%d %H:%M:%S")
    out = []
    out.append("(export (version D)")
    out.append('  (design (source "config.h master pin map") '
               f'(date "{ts}") (tool "gen_netlist.py"))')
    # components
    out.append("  (components")
    for ref, val, _fp, desc, _pins in COMPONENTS:
        out.append(f'    (comp (ref "{ref}")')
        out.append(f'      (value "{val}")')
        out.append(f'      (footprint "{F.footprint_of(ref)}")')
        out.append(f'      (description "{desc}"))')
    out.append("  )")
    # nets
    nets = build_nets()
    out.append("  (nets")
    for i, (net, nodes) in enumerate(nets.items(), start=1):
        out.append(f'    (net (code "{i}") (name "{net}")')
        for ref, pin_no, _pin_name in nodes:
            out.append(f'      (node (ref "{ref}") (pin "{pin_no}"))')
        out.append("    )")
    out.append("  )")
    out.append(")")
    with open(path, "w") as f:
        f.write("\n".join(out) + "\n")


def emit_markdown(path):
    nets = build_nets()
    lines = []
    lines.append("# Netlist — Urine Analyzer Lite (Design A)")
    lines.append("")
    lines.append("> Auto-generated by `gen_netlist.py` from the `config.h` master pin map.")
    lines.append("> For engineer verification. Footprints are placeholders — confirm in KiCad.")
    lines.append("")
    lines.append("## Components")
    lines.append("")
    lines.append("| Ref | Value | Footprint | Description |")
    lines.append("|---|---|---|---|")
    for ref, val, _fp, desc, _pins in COMPONENTS:
        lines.append(f"| {ref} | {val} | `{F.footprint_of(ref)}` | {desc} |")
    lines.append("")
    lines.append("## Nets")
    lines.append("")
    lines.append("| Net | Connections (ref.pin = name) |")
    lines.append("|---|---|")
    for net, nodes in nets.items():
        conns = ", ".join(f"{r}.{p} ({n})" for r, p, n in nodes)
        lines.append(f"| **{net}** | {conns} |")
    lines.append("")
    lines.append(f"_Total: {len(COMPONENTS)} components, {len(nets)} nets._")
    with open(path, "w") as f:
        f.write("\n".join(lines) + "\n")


if __name__ == "__main__":
    import os
    here = os.path.dirname(os.path.abspath(__file__))
    emit_kicad_net(os.path.join(here, "urine_analyzer_lite.net"))
    emit_markdown(os.path.join(here, "NETLIST.md"))
    nets = build_nets()
    print(f"Wrote netlist: {len(COMPONENTS)} components, {len(nets)} nets.")

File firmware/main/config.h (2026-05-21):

#pragma once
#include <Arduino.h>

// Pin map = hardware/ENGINEERING_REVIEW.md §3 (master, ESP32-S3, USB-CDC enabled).
// Avoids strapping pins (0/3/45/46), USB pins (19/20), and non-existent S3 pins (22–25).
// PENDING ELECTRONICS-ENGINEER VERIFICATION before PCB layout.

// ── I2C (shared bus: TCA9548A mux, SHT31, BH1750, ADS1115) ───────────────────
#define PIN_SDA    1
#define PIN_SCL    2

// ── Motor & encoder (N20 + MX1508) ───────────────────────────────────────────
#define PIN_MOTOR_IN1   4   // PWM
#define PIN_MOTOR_IN2   5   // PWM
#define PIN_ENC_A       6
#define PIN_ENC_B       7

// ── Limit switches (INPUT_PULLUP, active LOW) ────────────────────────────────
#define PIN_LIMIT_HOME 10
#define PIN_LIMIT_END  11

// ── LED illumination (PWM via 2N7000) ─────────────────────────────────────────
#define PIN_LED_PWM    12
#define LED_PWM_CHAN    0
#define LED_PWM_FREQ    5000
#define LED_PWM_RES     8    // 8-bit: 0–255

// ── UV-C enable (active HIGH; external 10k pull-DOWN → OFF at boot, safety) ───
#define PIN_UVC_EN     13
#define UVC_STERILIZE_MS  10000   // 10 s exposure

// ── HX711 load cell ──────────────────────────────────────────────────────────
#define PIN_HX711_DT   14
#define PIN_HX711_SCK  15

// ── UART1: thermal printer (CSN-A2) ──────────────────────────────────────────
#define PIN_PRINTER_TX 17   // MCU TX → printer RXD
#define PIN_PRINTER_RX 18   // printer TXD → MCU RX
#define PRINTER_BAUD    9600

// ── UART: debug / log ────────────────────────────────────────────────────────
#define SERIAL_BAUD     115200

// ── UI button ────────────────────────────────────────────────────────────────
#define PIN_SCAN_BTN   16    // INPUT_PULLUP, active LOW

// ── Display: SPI TFT 3.5–4.0" (ILI9488/ST7796) + XPT2046 touch (polled) ──────
// Touch shares the SPI bus (SCLK/MOSI/MISO); touch IRQ polled to save a pin.
#define PIN_TFT_SCLK   38
#define PIN_TFT_MOSI   39
#define PIN_TFT_MISO   40   // shared with touch read
#define PIN_TFT_CS     41
#define PIN_TFT_DC     42
#define PIN_TFT_BL     47   // backlight enable / PWM
#define PIN_TOUCH_CS   48
#define PIN_TFT_RST    21

// ── ADS1115 ──────────────────────────────────────────────────────────────────
#define ADS_ADDR        0x48
#define ADS_GAIN        1    // ±4.096 V

// ── I2C mux + TCS34725 ────────────────────────────────────────────────────────
// Two TCS34725 share fixed address 0x29 → each sits behind its own TCA9548A channel.
#define TCA9548A_ADDR   0x70
#define TCS_MUX_CH0     0    // primary RGB sensor
#define TCS_MUX_CH1     1    // secondary / differential RGB sensor
#define TCS_ADDR        0x29

// ── SHT31 ────────────────────────────────────────────────────────────────────
#define SHT31_ADDR      0x44

// ── BH1750 ───────────────────────────────────────────────────────────────────
#define BH1750_ADDR     0x23  // ADDR pin = GND

// ── Motor positioning ─────────────────────────────────────────────────────────
#define MOTOR_SPEED_HOME   150   // PWM duty for homing (0–255)
#define MOTOR_SPEED_SCAN   100   // PWM duty during scan
#define TICKS_PER_PAD       80   // encoder ticks per reagent pad (~2 mm)
#define NUM_PADS            10   // standard 10-pad dipstick

// ── Calibration ───────────────────────────────────────────────────────────────
#define CAL_R_WHITE    255
#define CAL_G_WHITE    255
#define CAL_B_WHITE    255

// ── Diagnostics ───────────────────────────────────────────────────────────────
struct PadResult {
    uint8_t  pad;
    uint16_t r, g, b, c;
    float    hue, sat, val;
    char     analyte[24];
    char     result[16];
};

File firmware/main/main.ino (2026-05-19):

/*
 * Urine Analyzer Lite — Main Firmware
 * Target: ESP32-S3-DevKitC-1 (Arduino ESP32 core ≥ 2.0.14)
 *
 * Required libraries (install via Arduino Library Manager):
 *   Adafruit TCS34725      >= 1.4.2
 *   Adafruit ADS1X15       >= 2.5.0
 *   Adafruit SHT31         >= 2.2.2
 *   BH1750                 >= 1.3.0
 *   HX711 by bogde         >= 0.7.5
 *
 * Board settings:
 *   Board     : ESP32S3 Dev Module
 *   Flash     : 8MB
 *   PSRAM     : OPI PSRAM
 *   USB Mode  : Hardware CDC and JTAG
 */

#include <Wire.h>
#include "config.h"
#include "sensors.h"
#include "motor.h"
#include "analysis.h"
#include "printer.h"

// ── State machine ─────────────────────────────────────────────────────────────
enum State { IDLE, HOMING, SCANNING, PRINTING, STERILIZING, ERROR_STATE };
static State state = IDLE;

// ── Scan results ──────────────────────────────────────────────────────────────
static PadResult results[NUM_PADS];
static uint8_t   pad_count = 0;

// ── LED PWM ───────────────────────────────────────────────────────────────────
void led_init() {
    ledcSetup(LED_PWM_CHAN, LED_PWM_FREQ, LED_PWM_RES);
    ledcAttachPin(PIN_LED_PWM, LED_PWM_CHAN);
    ledcWrite(LED_PWM_CHAN, 0);
}

void led_set(uint8_t duty) { ledcWrite(LED_PWM_CHAN, duty); }

// ── UV-C control ──────────────────────────────────────────────────────────────
void uvc_init()   { pinMode(PIN_UVC_EN, OUTPUT); digitalWrite(PIN_UVC_EN, LOW); }
void uvc_on()     { digitalWrite(PIN_UVC_EN, HIGH); }
void uvc_off()    { digitalWrite(PIN_UVC_EN, LOW); }

// ── Scan button ───────────────────────────────────────────────────────────────
void btn_init()   { pinMode(PIN_SCAN_BTN, INPUT_PULLUP); }
bool btn_pressed() { return digitalRead(PIN_SCAN_BTN) == LOW; }

// ── Single-pad scan ───────────────────────────────────────────────────────────
void scan_pad(uint8_t pad_idx) {
    led_set(200);
    delay(50);  // settle

    uint16_t r, g, b, c;
    read_rgb(r, g, b, c);
    led_set(0);

    float rn, gn, bn;
    normalise_rgb(r, g, b, c, rn, gn, bn);

    float h, s, v;
    rgb_to_hsv(rn, gn, bn, h, s, v);

    PadResult &res = results[pad_idx];
    res.pad = pad_idx + 1;
    res.r = r; res.g = g; res.b = b; res.c = c;
    res.hue = h; res.sat = s; res.val = v;

    classify_pad(res, h);

    Serial.printf("[PAD %2d] %s → %s  (H=%.1f S=%.2f V=%.2f)\n",
                  res.pad, res.analyte, res.result, h, s, v);
}

// ── Full scan sequence ────────────────────────────────────────────────────────
bool run_scan() {
    Serial.println("[SCAN] Homing...");
    if (!motor_home()) {
        Serial.println("[ERR] Homing failed");
        return false;
    }
    delay(200);

    pad_count = 0;
    for (uint8_t i = 0; i < NUM_PADS; i++) {
        Serial.printf("[SCAN] Moving to pad %d\n", i + 1);
        if (!motor_move_ticks(TICKS_PER_PAD)) {
            Serial.printf("[WARN] Motor end-stop at pad %d\n", i + 1);
            break;
        }
        delay(100);
        scan_pad(i);
        pad_count++;
    }

    motor_home();
    return pad_count > 0;
}

// ── Print report ──────────────────────────────────────────────────────────────
void print_report() {
    float temp    = read_temperature();
    float humidity= read_humidity();
    float weight  = read_weight_grams();
    printer_report(results, pad_count, temp, humidity, weight);
}

// ── UV-C sterilization cycle ──────────────────────────────────────────────────
void sterilize() {
    Serial.println("[UVC] Sterilization start");
    uvc_on();
    delay(UVC_STERILIZE_MS);
    uvc_off();
    Serial.println("[UVC] Sterilization done");
}

// ── Setup ─────────────────────────────────────────────────────────────────────
void setup() {
    Serial.begin(SERIAL_BAUD);
    delay(500);
    Serial.println("\n=== Urine Analyzer Lite ===");

    Wire.begin(PIN_SDA, PIN_SCL);
    Wire.setClock(400000);

    led_init();
    uvc_init();
    btn_init();
    motor_init();
    printer_init();

    if (!sensors_init()) {
        Serial.println("[WARN] Some sensors missing — check wiring");
    }

    Serial.println("[OK] Ready. Press scan button to begin.");
    state = IDLE;
}

// ── Loop ──────────────────────────────────────────────────────────────────────
void loop() {
    switch (state) {
        case IDLE:
            if (btn_pressed()) {
                delay(50);  // debounce
                if (btn_pressed()) {
                    float w = read_weight_grams();
                    if (w < 1.0f) {
                        Serial.println("[WARN] No sample detected. Place cup on scale.");
                        delay(2000);
                        break;
                    }
                    Serial.printf("[INFO] Sample %.1f g detected. Starting scan.\n", w);
                    state = HOMING;
                }
            }
            break;

        case HOMING:
            state = SCANNING;
            break;

        case SCANNING:
            if (run_scan()) {
                state = PRINTING;
            } else {
                Serial.println("[ERR] Scan failed");
                state = ERROR_STATE;
            }
            break;

        case PRINTING:
            print_report();
            state = STERILIZING;
            break;

        case STERILIZING:
            sterilize();
            Serial.println("[OK] Cycle complete. Remove strip. Ready.");
            state = IDLE;
            break;

        case ERROR_STATE:
            led_set(128);
            delay(500);
            led_set(0);
            delay(500);
            if (btn_pressed()) { state = IDLE; }
            break;
    }
}

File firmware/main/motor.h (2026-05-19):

#pragma once
#include <Arduino.h>
#include "config.h"

volatile long enc_ticks = 0;

void IRAM_ATTR enc_isr() {
    enc_ticks += (digitalRead(PIN_ENC_B) == HIGH) ? 1 : -1;
}

void motor_init() {
    pinMode(PIN_MOTOR_IN1, OUTPUT);
    pinMode(PIN_MOTOR_IN2, OUTPUT);
    ledcSetup(1, 20000, 8);          // channel 1 for motor PWM
    ledcAttachPin(PIN_MOTOR_IN1, 1);

    pinMode(PIN_ENC_A, INPUT_PULLUP);
    pinMode(PIN_ENC_B, INPUT_PULLUP);
    attachInterrupt(digitalPinToInterrupt(PIN_ENC_A), enc_isr, RISING);

    pinMode(PIN_LIMIT_HOME, INPUT_PULLUP);
    pinMode(PIN_LIMIT_END,  INPUT_PULLUP);
}

void motor_stop() {
    ledcWrite(1, 0);
    digitalWrite(PIN_MOTOR_IN2, LOW);
}

// Forward = away from home; duty 0–255
void motor_forward(uint8_t duty) {
    digitalWrite(PIN_MOTOR_IN2, LOW);
    ledcWrite(1, duty);
}

// Reverse = toward home
void motor_reverse(uint8_t duty) {
    digitalWrite(PIN_MOTOR_IN2, HIGH);
    ledcWrite(1, 255 - duty);
}

// Drive to home position; returns false if limit not hit within timeout_ms
bool motor_home(uint32_t timeout_ms = 10000) {
    enc_ticks = 0;
    uint32_t t0 = millis();
    motor_reverse(MOTOR_SPEED_HOME);
    while (digitalRead(PIN_LIMIT_HOME) == HIGH) {
        if (millis() - t0 > timeout_ms) { motor_stop(); return false; }
        delay(5);
    }
    motor_stop();
    enc_ticks = 0;
    delay(100);
    return true;
}

// Move forward by n_ticks encoder counts; returns false on end-limit hit
bool motor_move_ticks(long n_ticks, uint32_t timeout_ms = 15000) {
    long target = enc_ticks + n_ticks;
    uint32_t t0 = millis();
    motor_forward(MOTOR_SPEED_SCAN);
    while (enc_ticks < target) {
        if (digitalRead(PIN_LIMIT_END) == LOW) { motor_stop(); return false; }
        if (millis() - t0 > timeout_ms)        { motor_stop(); return false; }
        delay(2);
    }
    motor_stop();
    return true;
}

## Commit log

2026-05-19 Initial commit: Urine Analyzer Lite hardware, firmware, and BOM
    - KiCad schematic (16 components: ESP32-S3, dual TCS34725, SHT31, BH1750, ADS1115, N20+MX1508, TP4056, LiPo, S13V25F5, HX711, CSN-A2 printer, DSI LCD, UV-C LED)
    - OpenSCAD enclosure (9 3D-printable parts: chassis, optical chamber, dipstick tray, MCU tray, printer bracket, display bezel, UV-C shield, belt tensioner, limit switch brackets)
    - Arduino ESP32-S3 firmware: state machine, sensor drivers, encoder-based motor control, HSV pad classification for 10 analytes, ESC/POS thermal print
    - BOM CSV: ~40 line items, ~$387 prototype unit cost
    - TODO.md: complete hardware/firmware/procurement/regulatory checklist
    - README.md: setup, c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
    [bom.csv, main_chassis.scad, urine_analyzer_lite.kicad_sch]
2026-05-19 bom: replace US sourcing with India-specific suppliers and INR pricing
    - All 40 line items now show Indian supplier (Robocraze, Evelta, Probots,
    Electronicscomp, Mouser.in, Mouser India, Merck India, Amazon.in, etc.)
    - Unit and total costs in INR (₹84/USD basis)
    - Sourcing notes on each row: alternatives, availability caveats, bulk tips
    - Flagged 3 import-only parts: S13V25F5 (Mouser.in), 275nm UVC LED (Mouser.in),
    Spectralon standard (direct from Labsphere) with DIY/local alternatives noted
    - Total prototype BOM: ₹26,156 (~$311 USD) vs prior $387 US estimate
    [bom.csv]
2026-05-19 docs: add PDF exports for BOM, README, TODO + merged combined doc
    - docs/bom.pdf — India-sourced BOM as formatted landscape table (12 KB)
    - docs/readme.pdf — Project overview, setup, calibration, operation (9 KB)
    - docs/todo.pdf — Full project checklist with tick states (8 KB)
    - docs/urine_analyzer_lite_docs.pdf — All three merged, 9 pages (27 KB)
    - docs/gen_pdf.py — ReportLab generator script (regenerate: python3 docs/gen_pdf.py)
2026-05-21 Add Stage 0 regulatory foundation, SciSpace research, and Blueprint design
    - regulatory/: TPP, CDSCO classification (Class B), standards matrix,
    ISO 14971 risk file, preliminary FTO patent search + index
    - research/scispace/: SciSpace literature + manufacturing/commercial report (2P/10P, India market)
    - design/blueprint/: Blueprint lite-variant export (config, connections, parts, guide, visual)
    - TODO.md: regulatory section updated to reflect Stage 0 backfill + gating decisions
    [PARTS.csv, combined_urine_analyzer_results.csv, pubmed_urine_analyzer.csv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]
2026-05-21 Stage 4: reconcile electrical sources into master pin map + power budget
    - hardware/ENGINEERING_REVIEW.md: reconcile config.h / Blueprint / BOM (they conflict);
    adopt config.h as source of truth; flag hardware-validity bugs (invalid GPIO22, USB-pin
    printer RX, strapping-pin UV-C, dual-0x29 TCS34725, unbuildable DSI display); propose
    verified ESP32-S3 master pin map
    - hardware/POWER_BUDGET.md: rail analysis; missing 3.3V rail + 9V printer rail; regulator
    headroom marginal vs ~3.9A peak; battery C-rating + load-sequencing actions
    - TODO.md: add Stage 4 gate + blocking engineer-decision items
2026-05-21 Stage 4: lock display (SPI TFT) and apply master pin map to sources
    - config.h: adopt ENGINEERING_REVIEW §3 master pin map (fixes invalid GPIO22 SCL,
    USB-pin printer RX, strapping-pin UV-C); add SPI TFT (ILI9488) + XPT2046 touch pins
    and TCA9548A mux defines for the two TCS34725
    - bom.csv: replace 4.3" DSI LCD with 3.5" SPI TFT; add TCA9548A I2C mux and AMS1117-3.3
    - ENGINEERING_REVIEW.md: mark display resolved, fill concrete SPI pins
    - README.md: update display spec
    All pin assignments are valid free ESP32-S3 GPIOs. Pending engineer verification before layout.
    [bom.csv]
2026-05-21 Stage 4: generate netlist from master pin map
    - hardware/netlist/gen_netlist.py: single-source component/pin/net model (Design A)
    - urine_analyzer_lite.net: KiCad-importable netlist (Pcbnew Import Netlist) — path to layout
    - NETLIST.md: human-readable component + net table for engineer verification
    - README: engineer workflow (import .net, assign footprints, draw schematic, ERC, DRC, Gerbers)
    - 31 components, 39 nets; adds power path, bulk caps, LED MOSFET driver, UV-C EN pulldown,
    NTC divider, TCA9548A mux + dual TCS34725, SPI TFT + touch
    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
2026-05-21 Stage 4: generate ERC-validated KiCad schematic from netlist model
    - hardware/schematic/gen_schematic.py: rewritten to emit a real, connected schematic
    (replaces the old graphical mock-up generator); imports ../netlist model as source of truth
    - urine_analyzer_lite.kicad_sch: machine-generated, connection-by-global-label
    - Validated with KiCad 10 kicad-cli: ERC 0 errors; exported netlist matches model 39/39 nets
    - Add rendered PDF + ERC_report.txt + README explaining validation and engineer next steps
    Generic embedded symbols + placeholder footprints (the 59 ERC warnings) are for the engineer
    to replace/assign. Electrically correct per the model; physical design needs engineer sign-off.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
    [urine_analyzer_lite.kicad_sch]
2026-05-21 Stage 4: real symbols + footprints, and a starting PCB
    - hardware/footprints.py: real KiCad footprints for all 31 parts (modules = 2.54mm pin
    headers, pin order to verify vs datasheets; LED/TO-92 pad overrides)
    - schematic: 14 jellybean discretes now use real Device:/Switch: library symbols (embedded);
    modules/MOSFET stay custom but numbered by PCB pad; every part carries a real footprint.
    ERC 0 errors; netlist matches model 39/39 by ref+pad
    - hardware/pcb/: starting board built via pcbnew Python (build_pcb.py) — 31 footprints
    placed + net-assigned + outline; schematic-parity 0; unrouted ratsnest + cosmetic auto-grid
    DRC only. Includes project, 3D render, DRC report
    - netlist gen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
    [urine_analyzer_lite.kicad_pcb, urine_analyzer_lite.kicad_sch]
2026-05-21 Add project status & engineering report (HTML + PDF)
    Comprehensive report: device spec, stage status, Stage 0 regulatory foundation,
    Stage 4 engineering (source reconciliation, bugs fixed, decisions locked, validated
    schematic/netlist/PCB), open decisions, and next steps (engineer close-out + Stages 5-12).
2026-05-24 hardware: real KiCad project built via kicad-mcp — ERC 0 errors
    - hardware/kicad_project/ — new KiCad 10 project with real library symbols
    - 34 components placed from KiCad libraries (no hand-written S-expressions):
    U1: RF_Module:ESP32-S3-WROOM-1
    U2: Interface_Expansion:TCA9548APWR (I2C mux for dual TCS34725)
    U3: Sensor_Humidity:SHT31-DIS
    U4: Analog_ADC:ADS1115IDGS
    U5: Analog_ADC:HX711
    U6: Battery_Management:TP4056-42-ESOP8
    Q1: Transistor_FET:2N7000
    J1-J10: Connector_Generic headers for breakout modules
    SW1-SW3: Switch:SW_Push (KW12-3 limits + scan button)
    D1, D2: Device:LED (High-CRI + UV-C)
    R1-R5, RT1, C1-C2, BT1: passives
    #FLG01-06: powe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
    [urine_analyzer_lite.kicad_pcb, urine_analyzer_lite.kicad_sch]

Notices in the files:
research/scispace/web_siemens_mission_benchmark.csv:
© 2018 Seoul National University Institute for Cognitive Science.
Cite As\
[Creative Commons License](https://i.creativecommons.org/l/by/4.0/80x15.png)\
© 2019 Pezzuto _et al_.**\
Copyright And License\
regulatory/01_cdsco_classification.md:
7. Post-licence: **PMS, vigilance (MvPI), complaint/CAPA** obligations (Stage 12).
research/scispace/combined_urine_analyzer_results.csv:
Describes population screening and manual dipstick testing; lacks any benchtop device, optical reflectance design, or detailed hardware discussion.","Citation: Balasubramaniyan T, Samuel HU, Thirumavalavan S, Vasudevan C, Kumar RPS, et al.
